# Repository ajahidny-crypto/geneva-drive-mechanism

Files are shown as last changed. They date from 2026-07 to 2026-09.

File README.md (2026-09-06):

# 4-Slot Geneva Drive 

A mechanical engineering project where I designed, calculated, 3D printed, and tested a four-slot Geneva drive.

The main version of the mechanism is hand-spun. I also modified the CAD files for a NEMA 17 stepper motor, but I have not yet built and tested the motorized version, however, I'm positive it will transition smoothly.

## What is a Geneva Drive?

A Geneva drive converts continuous rotation into intermittent motion. The driver rotates continuously, while the Geneva wheel moves one position at a time and then locks in place. 

I chose to build one because it is a fairly simple mechanism to understand, but even the smallest mathematical  or clearance error can make a big difference once the parts are printed and assembled/

#Design

I designed the mechanism in Fusion 360 and printed the parts in PETG on a Bambu Lab P1S.

The design uses four slots, so the Geneva wheel rotates 90° each time it is turned.

| Parameter | Value |
|---|---|
| Slots (n) | 4 |
| Driven wheel radius (b) | 50.00 mm |
| Drive crank radius (a) | 50.00 mm |
| Center distance (C) | 70.71 mm |
| Pin diameter | 6.00 mm |
| Slot width | 6.35 mm |
| Design clearance (PETG) | 0.35 mm |
| Plate thickness | 8.00 mm |
| Locking wall diameter (as-tuned) | 80.50 mm |

The calculations and dimensions are included in the spreadsheet in this repository.

## Working Through the Geometry

My first set of dimensions had failed.

The crank radius and the Geneva wheel geometry did not allow the pin to reach the slots correctly. After going back through the geometry, I found that the four slot design required the crank radius to match the driven wheel radius.

I rebuilt the dimensions using the geometry of a four-slot Geneva mechanism and then checked the results against a published Geneva wheel design from FreeCAD.

This was a much better starting point for me.

## The Locking Mechanism

The locking mechanism was the part that was the most tedious.

My first design used a recessed area on the driver wheel to lock the Geneva wheel between rotations. It looked correct at one position, but once I printed it and turned the mechanism, the two parts interfered with each other at the points of rotation.

From what I understood, the problem was that I shaped the locking surface around the wrong center.

I went back to the standard geometry used in Geneva mechanisms and redisgned the 

I went back to the standard geometry used in Geneva mechanisms and redesigned the driver with a raised locking section and an opening for the Geneva wheel to pass through.

I also calculated the opening using the intersection of two circles instead of estimating the shape by eye.

The new print worked much better. There was still some grinding during the locking portion of the motion, so I traced the problem to the clearance around the locking wall. I reduced its diameter by 0.5 mm and printed it again.

After that adjustment, the mechanism moved smoothly by hand.

##Physical Testing

The final mechanical version was tested by hand.

I checked that:

The Geneva wheel moves through all four positions.
The wheel locks between each position.
The pin enters and leaves the slots without getting stuck.
The mechanism can complete repeated rotations.
The printed parts have enough clearance to move without excessive friction.

The final version successfully completes the four-position indexing cycle by hand.

##NEMA 17 Version

I also created a modified version of the CAD design for a NEMA 17 stepper motor.

The repository includes:

Modified Fusion 360 assemblies
STEP files
STL files
A preliminary Arduino .ino file

The motorized version is not currently completed or physically tested. The main mechanism in this project is still the hand-spun version.

I included the motor-compatible files because I want to eventually automate the mechanism and test how well the printed Geneva drive performs under continuous motor-driven rotation.

Files
File	Description
GenevaCADfile.f3z	Original Fusion 360 assembly
GenevaCADfiles.step	STEP version of the Geneva drive
GenevaCADfiles.stl	STL files for 3D printing
Geneva_Drive_Calculator_1.xlsx	Design calculations and dimensions
Geneva_Sideview.png	Side view of the design
Geneva_Topview.png	Top view of the design
Nema - 17 - Geneva Drive'.stl	Modified STL for NEMA 17 integration
Nema 17 - Geneva Drive.step	Modified STEP model
Nema 17 - Geneva Drive.f3z	Modified Fusion 360 assembly
nema17_geneva_driver.ino	Preliminary Arduino motor-control code
LICENSE	Project license
Tools and Materials
Fusion 360
Bambu Lab P1S
PETG
3D printing
Excel
Arduino files for future motor integration
FreeCAD for checking the Geneva mechanism geometry
What I Learned

This project taught me that getting the math right is only part of designing a mechanical system.

My first design looked reasonable on paper, but the printed parts showed problems that were not obvious from the original model. I had to go back to the geometry, figure out why the parts were interfering, change the design, print it again, and test it.

The locking mechanism was especially useful because the first version technically looked like it should work, but physical testing showed that it didn't.

That process of designing, printing, testing, finding a problem, and changing the design is what I wanted to document with this project.

Future Plans

The next step is to finish the NEMA 17 version and test the Geneva drive under motor power.

I would also like to experiment with different print clearances and materials to see how they affect friction, movement, and the locking mechanism.

License

This project is open source. See the LICENSE file for the license terms.

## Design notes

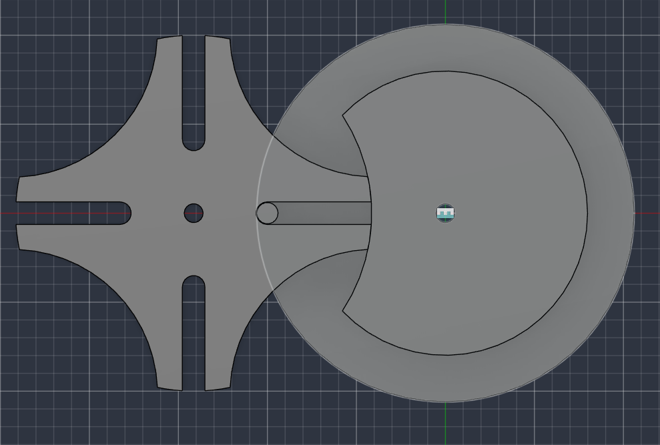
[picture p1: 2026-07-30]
Geneva_Topview.png

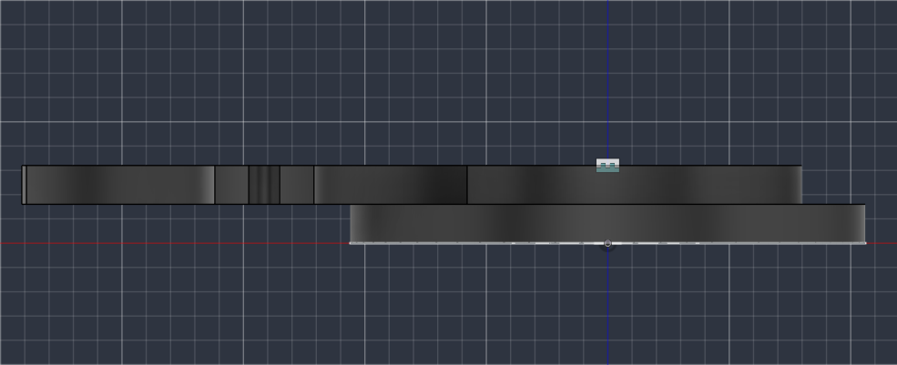
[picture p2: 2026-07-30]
Geneva_Sideview.png

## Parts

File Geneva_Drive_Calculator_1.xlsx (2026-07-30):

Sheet: Calculator
Geneva Drive Mechanism — Design Calculator
4-slot external Geneva drive, sized for FDM printing (Bambu Lab P1S / PETG), NEMA 17 driver
Blue cells are yours to edit — change one and everything else updates on its own. Black cells are calculated for you, so no need to touch those.
INPUTS — GENEVA GEOMETRY
Geneva Wheel Radius (b) | 50.0000 mm | How big the star wheel is, measured from its center out to the edge.
Number of Slots (n) | 4 | How many slots are cut into the star wheel — also how many steps it takes to spin all the way around.
Pin Diameter (p) | 6.0000 mm | How thick the little peg is that pushes the star wheel along.
Clearance (t) | 0.3500 mm | A bit of built-in wiggle room in every fit, so PETG parts don't drag or bind after printing.
Plate Thickness (h) | 8.0000 mm | How tall each wheel is, top to bottom. This one's just your own choice, not something the geometry forces on you.
CORE GENEVA GEOMETRY (calculated)
Half-Angle (λ = 180/n) | 45.000 deg | Half the angle between two slots. Just a helper number the other formulas lean on.
Drive Crank Radius (a) | 50.0000 mm | How far the pin sits from the center of the drive wheel.
Center Distance (C) | 70.7107 mm | How far apart the two wheels' centers need to be mounted from each other.
Slot Center Length (s) | 29.2893 mm | How deep each slot needs to be so the pin can travel all the way in and back out.
Slot Width (w) | 6.3500 mm | How wide to cut each slot so the pin slides through without binding.
Stop Arc Radius (y) | 41.0000 mm | Size of the locking pocket that keeps the star wheel from drifting when it's not being pushed.
Stop Disc Radius (z) | 40.6500 mm | Size of the matching locking piece on the drive wheel that sits inside that pocket.
Clearance Arc (v) | 40.6500 mm | A backup reference size for the same locking fit — same idea as the two above.
Engagement Half-Angle (α) | 45.000 deg | How far the drive wheel turns, in degrees, while it's actually pushing the star wheel.
Dwell Half-Angle (β) | 135.000 deg | How far the drive wheel turns while the star wheel just sits locked, waiting for the next push.
Star Wheel Outer Diameter | 100.0000 mm | The full width of the star wheel, edge to edge.
MOTOR / SHAFT INTERFACE
Shaft Diameter (nominal) | 5.0000 mm | How thick the motor's actual metal shaft is.
Bore Diametral Clearance | 0.3000 mm | A little extra room added to the hole so it slides onto the shaft freely.
Bore Diameter | 5.3000 mm | How big to make the center hole so the shaft actually fits through it.
Shaft Flat Dimension (D) | 4.5000 mm | Straight from the motor's spec sheet — describes the flat side ground into the shaft.
Flat Depth from Center | 2.0000 mm | How far in to cut that flat surface, so the hole grips the motor's flat-sided shaft instead of spinning loose around it.
Pin Protrusion above plate | 1.2500 mm | How far the pin sticks up above the wheel's top surface.
Total Pin Height | 9.2500 mm | The pin's full height, from its base to its tip.
Star Wheel Bore Diameter | 5.3000 mm | Same hole size as the drive wheel — the star wheel just spins freely on its own rod, no motor attached.

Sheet: Formula Reference
Formula Reference — Derivations & Sources
# | Name | Formula | Source / Basis | Purpose
1 | Tangential entry condition | sin(λ) = a/C, λ = 180°/n | Classical Geneva/Maltese-cross mechanism kinematics | Ensures shock-free pin entry into the slot
2 | Crank radius | a = C × sin(λ) | Derived from #1 | Solves driver pin placement radius
3 | Driven wheel radius | b = C × cos(λ) | Derived from #1 | Solves star wheel engagement radius
4 | n=4 special identity | sin45° = cos45° → a = b | Trig identity — true only for the 4-slot case | Forces equal crank/wheel radii for n=4
5 | Crank radius (general form) | a = b × tan(λ) | Combining #2 and #3, solved for a in terms of b | Avoids circular a↔C dependency; used in Calculator tab
6 | Center distance | C = √(a² + b²) [= b×√2 when n=4] | Right-triangle relation from #2, #3 | Solves wheel spacing from chosen b
7 | Slot center length | s = a + b − C | Geometric — max pin travel inside slot | Sets slot depth (kinematic, before pin/clearance offset)
8 | Slot width | w = p + t | Manufacturing clearance | Pin diameter plus printer/material clearance
9 | Stop arc radius | y = a − 1.5×p | FreeCAD 'Geneva Wheel' macro convention (github.com/FreeCAD/FreeCAD-macros) | Sizes the locking pocket, offset clear of the pin boss
10 | Stop disc radius | z = y − t | Manufacturing clearance on #9 | Driver's locking disc — mates inside the locking pocket
11 | Clearance arc | v = b × z / a | FreeCAD 'Geneva Wheel' macro output (reference value) | Auxiliary reference dimension; equals z when a=b (n=4)
12 | Engagement / dwell angles | θ_engage = 180−2λ, θ_dwell = 360−θ_engage | Geometric analysis of the pin-in-slot triangle | Driver rotation while indexing vs. while locked/stationary
Core Geneva formulas (#1–7, #12): standard mechanism-design theory — cross-references cleanly to any machine-design textbook chapter on Geneva/Maltese-cross mechanisms (e.g. Norton, Design of Machinery; Shigley, Theory of Machines and Mechanisms).

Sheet: Build Notes
Build Notes — Key Issues Found & Resolved
Issue | What Was Found | Resolution
Initial crank radius (r = 20.71mm) | For a 4-slot Geneva, tangential entry mathematically requires the crank radius to equal the driven wheel radius exactly (a = b × tan(180/n), and tan45° = 1). The original value was actually C − b — a different geometric quantity — not a valid crank radius. | Recalculated with a = b = 50mm. Slot depth had already been sized correctly for this radius, so only the crank radius itself needed correcting.
Locking / stop-arc geometry | Hand-derived construction for the driver's locking disc did not fully match how these features are conventionally built. | Verified all core outputs (c, s, w, y, z, v) against the FreeCAD 'Geneva Wheel' macro (github.com/FreeCAD/FreeCAD-macros) — confirmed exact numeric match.
Driver locking-arc clearance cut | The exact 3D Boolean geometry for the driver/star-wheel locking interface proved difficult to reliably hand-derive in CAD from formulas alone. | Final geometry achieved through iterative alignment directly in Fusion 360 — visually fitting the driver's locking feature to the star wheel's between-slot arcs, then patterning. Verified functional by test print rather than by closed-form coordinates.
Final validation | — | Printed on a Bambu Lab P1S in PETG at 0.35mm design clearance. Mechanism indexes correctly through all four positions.

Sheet: Drive Wheel Bore
Drive Wheel — Center Bore (With & Without D-Flat)
Blue cells are yours to edit. Black cells calculate themselves — leave those alone and they'll stay accurate.
SHARED INPUTS
Shaft Diameter (nominal) | 5.0000 mm | How thick the motor's actual metal shaft is.
Bore Diametral Clearance | 0.3000 mm | A little extra room added to the hole so it slides onto the shaft freely.
Bore Diameter | 5.3000 mm | How big to make the center hole so the shaft actually fits through it.
WITHOUT D-FLAT — test build, mounted on plain rod
Bore Diameter | 5.3000 mm | How big to make the center hole so the shaft actually fits through it.
Shape | Plain round hole — no flat cut | What the hole itself looks like.
Fit Type | Free-spinning slip fit | How snugly this part is meant to sit on its shaft.
Fusion Method | Hole tool — Diameter above, Termination = All | Which tool to reach for in Fusion 360 to make this cut.
WITH D-FLAT — final build, keyed to NEMA 17 shaft
Bore Diameter (before flat cut) | 5.3000 mm | The hole's size before the flat is trimmed into one side of it.
Shaft Flat Dimension (D) | 4.5000 mm | Straight from the motor's spec sheet — describes the flat side ground into the shaft.
Flat Depth from Center | 2.0000 mm | How far in to cut that flat surface, so the hole grips the motor's flat-sided shaft instead of spinning loose around it.
Flat Chord Width | 3.0000 mm | How wide the flat cut ends up being, side to side, once it's trimmed in.
Flat Length along shaft | 15.0000 mm | How far back from the tip of the motor's shaft the flat extends — tells you how deep you can safely cut.
Shape | Circle with one flat chord (D-shape) | What the hole itself looks like.
Fit Type | Keyed press-fit onto motor's D-shaft | How snugly this part is meant to sit on its shaft.
QUICK CAD REFERENCE — Fusion 360
1. Sketch circle, diameter = Bore Diameter (above), centered at origin
2. [D-flat only] Draw a line crossing the circle; Sketch Dimension: origin to line = Flat Depth from Center
3. [D-flat only] Add Horizontal constraint to the line if not automatic
4. [D-flat only] Trim away the small arc segment beyond the line
5. Finish sketch
6. Without flat: Create > Hole, Termination = All
With flat: Create > Extrude (Cut), Termination = All

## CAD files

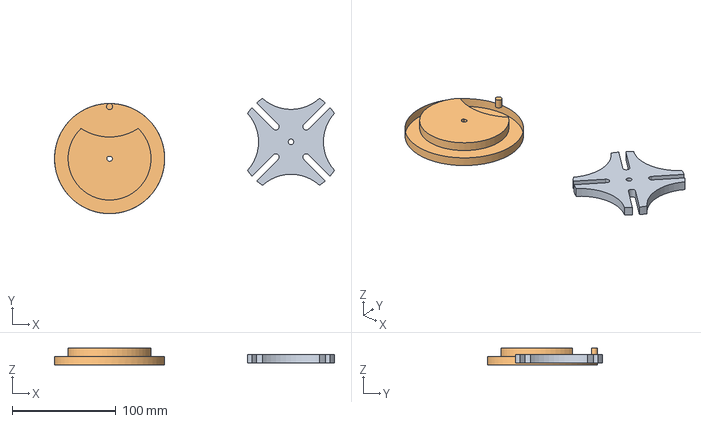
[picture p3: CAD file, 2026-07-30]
Nema 17 - Geneva Drive.step
269.4 x 110.9 x 16.0 mm

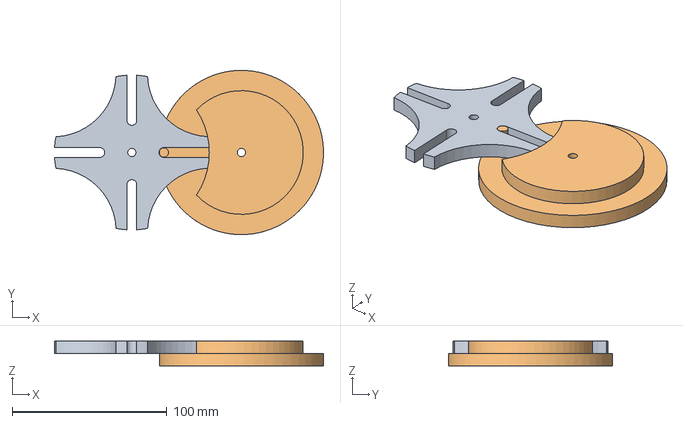
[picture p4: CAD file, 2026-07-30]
GenevaCADfiles.step
173.6 x 106.0 x 16.0 mm

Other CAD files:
GenevaCADfile.f3z
GenevaCADfiles.stl
Nema - 17 - Geneva Drive'.stl
Nema 17 - Geneva Drive.f3z

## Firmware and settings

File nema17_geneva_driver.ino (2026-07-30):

/*
  NEMA 17 Stepper Motor — Continuous Rotation
  Drives the Geneva mechanism's driver wheel

  HARDWARE NEEDED:
  - Arduino Uno/Nano/Mega (or compatible)
  - A4988 or DRV8825 stepper driver module
  - NEMA 17 stepper motor (bipolar, 4-wire — e.g. 17HS19-2004S1)
  - External power supply, 12-24V
    (DO NOT power the motor from the Arduino's 5V — it can't supply enough current)

  WIRING (A4988 / DRV8825 driver board):
    Driver VDD              -> Arduino 5V
    Driver GND (logic side) -> Arduino GND
    Driver STEP             -> Arduino pin 3
    Driver DIR              -> Arduino pin 4
    Driver VMOT             -> External power supply (+)
    Driver GND (motor side) -> External power supply (-), common with Arduino GND
    Driver 1A / 1B          -> Motor coil A (2 of the 4 motor wires)
    Driver 2A / 2B          -> Motor coil B (the other 2 motor wires)

  IMPORTANT - SET THE CURRENT LIMIT BEFORE RUNNING AT SPEED:
  This motor is rated for 2.0A. Most drivers ship set too high or unset.
  With the Arduino powered OFF, measure the driver's Vref at its small
  onboard potentiometer with a multimeter, and adjust it to match 2.0A
  using your specific driver's Vref formula (check its datasheet -
  the formula differs between A4988 and DRV8825).
  Running without setting this risks overheating the driver or motor.
*/

const int stepPin = 3;
const int dirPin  = 4;

const int stepsPerRevolution = 200;   // 1.8 deg step angle -> 200 full steps per revolution

int stepDelayMicros = 1000;           // Lower = faster rotation. Start high, decrease gradually.

void setup() {
  pinMode(stepPin, OUTPUT);
  pinMode(dirPin, OUTPUT);
  digitalWrite(dirPin, HIGH);         // HIGH = one direction, LOW = reverse
}

void loop() {
  digitalWrite(stepPin, HIGH);
  delayMicroseconds(stepDelayMicros);
  digitalWrite(stepPin, LOW);
  delayMicroseconds(stepDelayMicros);
}
